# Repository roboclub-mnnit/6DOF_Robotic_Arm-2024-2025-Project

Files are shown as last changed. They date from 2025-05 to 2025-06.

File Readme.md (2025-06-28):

# 6-DOF Robotic Arm Project

This repository contains code and documentation for a 6-Degree of Freedom (6DOF) robotic arm built using MG995/MG958 servo motors and Arduino UNO. The project implements inverse kinematics and forward kinematics for precise control of the arm's end-effector position in 3D space.

---

## 📑 Table of Contents

- Project Overview
- Repository Structure
- Hardware Requirements
- Software Requirements
- Installation and Setup
- Usage
- Coordinate System and Offsets
- Kinematics and Transformation Matrices
- Angle Ranges
- Photo Gallery
---

## 📌 Project Overview

This project demonstrates the design and development of a 6DOF robotic manipulator for industrial automation tasks. It offers ±2mm positioning accuracy with a 0.5 kg payload capacity. The arm is controlled via Arduino using trajectory planning based on inverse kinematics and includes simulation in Python.

---

## Repository Structure

- `Arduino Files/`

  - `Basecode`: Firmware for  move robotic arm to given position.
  - `CODE1`: Firmware for move the robotic arm to the given postion and return in its original position.
  - `CODE2`: Firmware for move the robotic arm to given postion and pick a object and return in its original position.
  - `FINAL`: Firmware for move robotic arm from its original postion pick object from a position and place it on another position and move back to it original position.

- `Python File/`

  - `kinematics/`
    - `Inverse Kinematics.py`: Script to compute six joint angles of the robotic arm.
  - `simulation/`
    - `Simulation.py`: 3D simulation of all joint of the Robotic arm.

- `Solidworks File/`

  - (Placeholder for SolidWorks design files, e.g., `.sldprt` or `.sldasm` files)

- `docs/`

  - `ReadMe.md`: Main project overview and instructions.
  - `arduino.md`: Detailed documentation for Arduino firmware.
  - `components.md`: Information on design specifications and hardware components.
  - `python.md`: Detailed documentation for Python simulation and kinematics scripts.

## 🔧 Hardware Components

- Arduino UNO
- MG995 / MG958 Servo Motors
- Jumper Wires & Breadboard
- 3D Printed Structural Parts
- SMPS Power supply (5V)
- Ball Bearings
- Gripper (optional)

---

## 💻 Software Stack

- Arduino IDE
- BLA Library (for multiplication of mtrix in Arduino IDE)
- Python (with Matplotlib, NumPy)
- SolidWorks (for modeling)
- Inverse Kinematics (custom script)
- Forward Kinematics (DH Parameter based)

---

## 📐 Kinematics and Control

We use Denavit-Hartenberg (D-H) parameters to derive transformation matrices for forward kinematics and solve inverse kinematics numerically for joint angle calculations. The control flow is as follows:

1. **Input Desired (x, y, z)**
2. **Calculate wrist center from gripper center coordinate**
3. **Calculate first three Joint Angles via IK**
4. **Find R3_6 matrix for last three joints angle**
5. **Write Python code for simulation**
6. **Move Servo Motors via Arduino**

---

## ⚙️ Installation & Setup

1. **Python Setup**:

   - Install Python 3.x.

   - Install libraries:

     ```bash
     pip install numpy matplotlib
     ```

2. **Arduino Setup**:

   - Install Arduino IDE from arduino.cc.
   - Connect servos to Arduino pins (default: 3,5,6, 9, 10, 11).
   - Upload the appropriate `.ino` file for each leg.

3. **Simulation**:

   - Run Python scripts for visualization.
   - Adjust joint angles using sliders.

4. **Physical Robot**:

   - Power servos and connect to Arduino.
   - Use Serial Monitor (9600 baud) to input coordinates.

## Usage

### Simulation

- Run `Simulation.py` for all joint angles:

  ```bash
  python Simulation.py
  ```

  - Adjust X, Y, Z,ROLL,PITCH ,YAW values via sliders.
  - Use XY, XZ, YZ buttons to change views.
  - View end effector coordinates on the plot.

### Inverse Kinematics

- Run `Inverse Kinematics.py`:

  ```bash
  python Inverse Kinematics.py
  ```

  - Input End Effector coordinates (x, y, z) and orientation of the End Effector (ROLL,PITCH,YAW).
  - Outputs theta1, theta2, theta3, theta4, theta5, theta6 in degrees.

### Arduino Control

- Upload `.ino` file for each leg.
- Open Serial Monitor (9600 baud).
- Enter x, y, z  coordinate and ROLL,PITCH,YAW values to move servos.

## Kinematics and Transformation Matrices

Link Length: `a1 = 5.38 cm`, `a2 = 0.0 cm`, `a3 = 11.217 cm`, `a4 = 12.876 cm`, `a5 = 4.405 cm`.

### Rotation Matrices

```python
R0_1 = np.array([[-np.sin(T1), 0, np.cos(T1)],
                 [np.cos(T1),  0, np.sin(T1)],
                 [0,           1,          0]])

R1_2 = np.array([[np.cos(T2), -np.sin(T2), 0],
                 [np.sin(T2),  np.cos(T2), 0],
                 [0,           0,          1]])

R2_3 = np.array([[1, 0, 0],
                 [0, 0, 1],
                 [0, -1, 0]])
```

### DH Parameter matrix 

```python
def DH_Params_H_Matrix(i,j,q1=0,q2=0,q3=0,q4=0,q5=0,q6=0):
    DH_params=np.array([
        [q1,np.pi/2,a2,a1],
        [q2,0,a3,0],
        [q3+np.pi/2,np.pi/2,0,0],
        [q4,-np.pi/2,0,a4],
        [q5,np.pi/2,0,0],
        [q6,0,0,a5]
    ])
    H_matrix= Matrix([
        [1, 0, 0, 0],
        [0, 1, 0, 0],
        [0, 0, 1, 0],
        [0, 0, 0, 1]                                                                                   
    ])
    for k in range(i,j):                                                                                                                             
        H2_matrix=Matrix([                                     
            [np.cos(DH_params[k,0]),-np.sin(DH_params[k,0])*np.cos(DH_params[k,1]),np.sin(DH_params[k,0])*np.sin(DH_params[k,1]),DH_params[k,2]*np.cos(DH_params[k,0])],
            [np.sin(DH_params[k,0]),np.cos(DH_params[k,1])*np.cos(DH_params[k,0]),-np.cos(DH_params[k,0])*np.sin(DH_params[k,1]),DH_params[k,2]*np.sin(DH_params[k,0])],
            [0,np.sin(DH_params[k,1]),np.cos(DH_params[k,1]),DH_params[k,3]],
            [0,0,0,1]
        ])
        H_matrix=np.dot(H_matrix,H2_matrix)         
    return np.matrix(H_matrix)
```

### Rotation Matrix

```python
def get_Joint_Variables(finalX, finalY, finalZ, roll, pitch, yaw):
    R0_6_initial = np.array([
        [0, 0, 1],
        [0, -1, 0],
        [1, 0, 0]
    ])

    R_6_rotation = np.array([
        [np.cos(pitch)*np.cos(roll), np.sin(pitch)*np.sin(yaw)-np.sin(roll)*np.cos(pitch)*np.cos(yaw), np.sin(pitch)*np.cos(yaw)+np.sin(roll)*np.sin(yaw)*np.cos(pitch)],
        [np.sin(roll),               np.cos(roll)*np.cos(yaw),                                         -np.sin(yaw)*np.cos(roll)],
        [-np.sin(pitch)*np.cos(roll),np.sin(pitch)*np.sin(roll)*np.cos(yaw)+np.sin(yaw)*np.cos(pitch), -np.sin(pitch)*np.sin(roll)*np.sin(yaw)+np.cos(pitch)*np.cos(yaw)]
    ])

    R0_6 = np.dot(R0_6_initial, R_6_rotation)
    print(R0_6)

```

## Photo Gallery

- Manipulator Diagram:
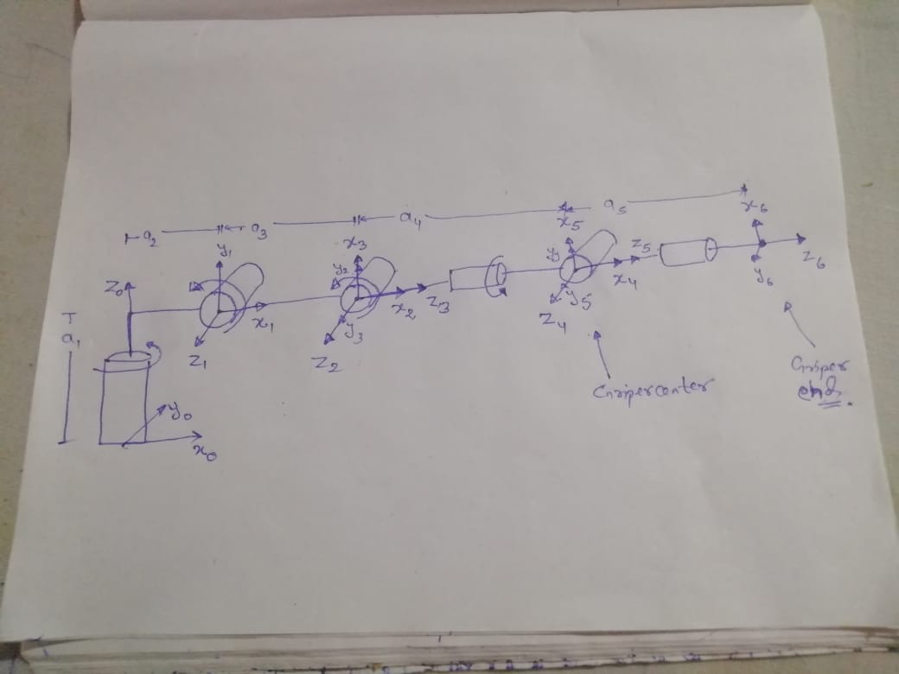
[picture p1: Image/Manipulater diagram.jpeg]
Manipulator diagram (2)
  

- Robotic Arm(Model):
  
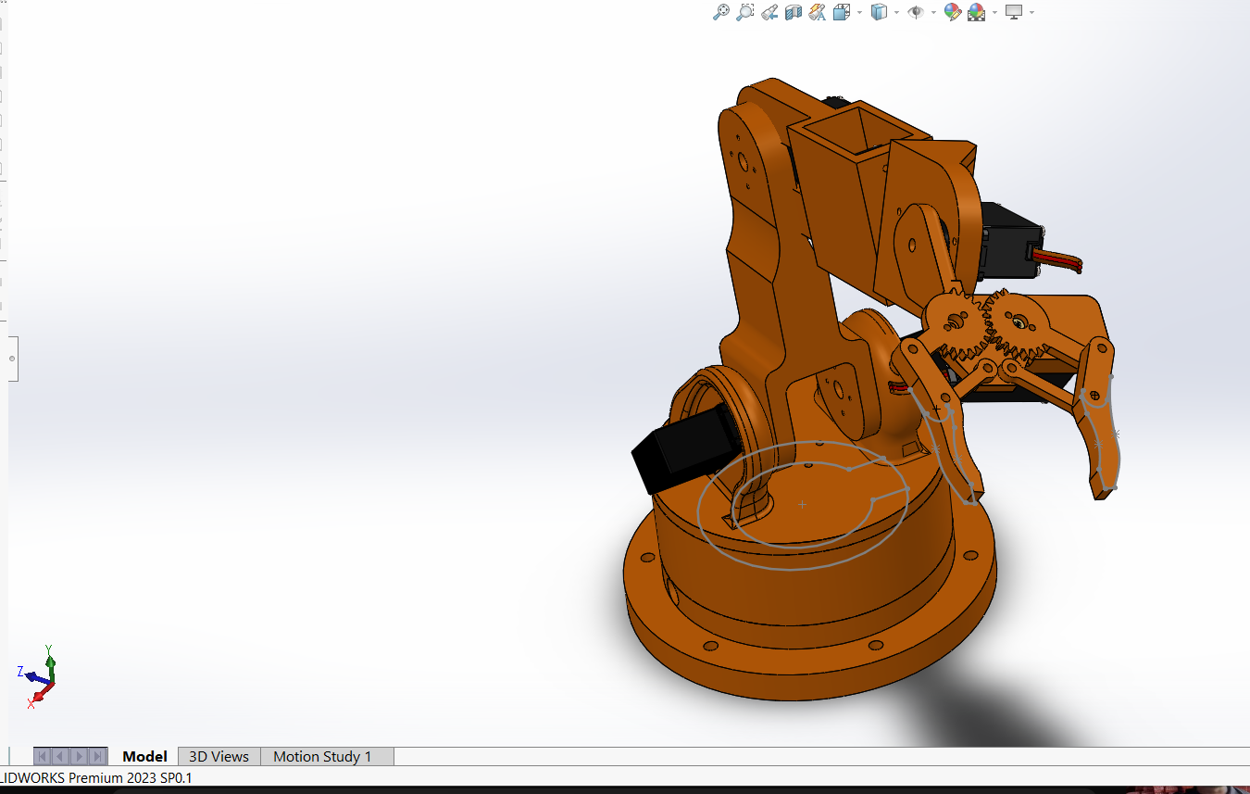
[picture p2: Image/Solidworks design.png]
Solidworks design of the 6DOFRobotic arm
  
- Robotic Arm(Actual Bot):
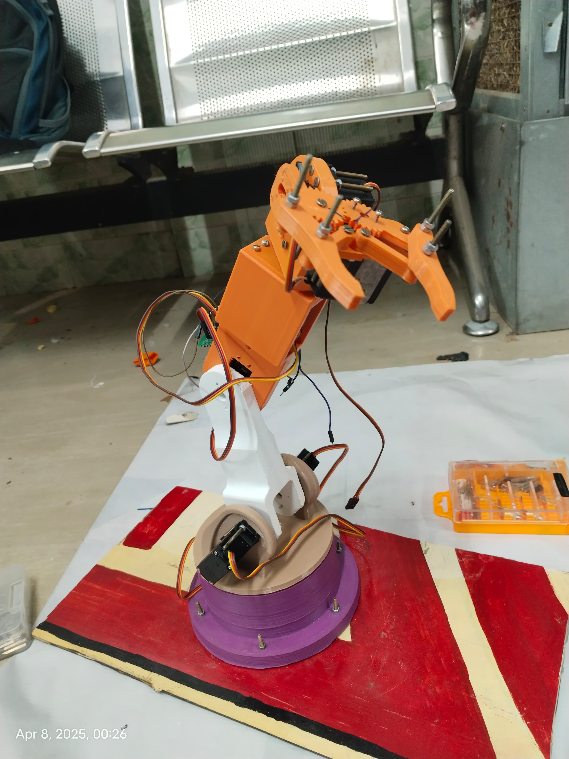
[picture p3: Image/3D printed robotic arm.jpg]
3D Printed Robotic arm


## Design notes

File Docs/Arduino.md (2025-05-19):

# Arduino Firmware Documentation

This document provides detailed explanations of the Arduino sketches used to control the 6DOF robotic arm via servo motors.

---

## 📁 Code Structure

### 🔹 `Basecode`

- **Functionality**: Moves the robotic arm to a given position based on user input (X, Y, Z, Roll, Pitch, Yaw).
- **Use Case**: For basic forward positioning.

### 🔹 `CODE1`

- **Functionality**: Moves the robotic arm to a target position and returns to the original starting position.
- **Use Case**: Simple pick-and-return operations.

### 🔹 `CODE2`

- **Functionality**: Moves the robotic arm to pick up an object and returns to its original position.
- **Use Case**: Object pickup and repositioning tasks.

### 🔹 `FINAL`

- **Functionality**: Fully automated pick-and-place operation. The arm moves from home position, picks the object, places it elsewhere, and returns.
- **Use Case**: Industrial-like automation for repetitive tasks.

---

## 🔧 Libraries Used

- **Servo.h**: For controlling servo motors.
- **BasicLinearAlgebra.h (BLA)**: Used for matrix multiplication and transformations.

---

## ⚙️ Pin Configuration

| Servo Motor | Pin Number (Default) |
|---|---|
| Base | 3 |
| Shoulder | 4,5 |
| Elbow | 6 |
| Wrist | 9 |
| Gripper | 10 |
| Rotator | 11 |

---

## 🌀 Operating Logic

1. Accept coordinates via Serial Monitor.
2. Compute required angles using inverse kinematics (in Python).
3. Pass angle values to servos.
4. Move arm to final position using the servo write command.
5. Optional: delay and return to home.

---

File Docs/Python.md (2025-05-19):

# Python Simulation and Kinematics Documentation

This file describes the Python scripts used to simulate and calculate the kinematics of the 6DOF robotic arm.

---

## 📂 Directory Structure

- `kinematics/`
  - `Inverse Kinematics.py`: Calculates the six joint angles using numerical inverse kinematics.
- `simulation/`
  - `4 Legs Simulation.py`: Generates a 3D simulation of the robotic arm’s motion using matplotlib.

---

## 🧠 Kinematics Theory

### ➤ Inverse Kinematics

The script receives:
- Target coordinates: (X, Y, Z)
- Orientation: (Roll, Pitch, Yaw)

And outputs:
- Joint angles: θ1 to θ6

It breaks down the solution in two stages:
1. **First Three Joints**: Uses geometric IK for shoulder, elbow, and base.
2. **Last Three Joints**: Uses rotation matrices to compute wrist orientation.

---

## 🧩 Libraries Used

- **NumPy**: For matrix computation
- **Matplotlib**: For 3D simulation and visualization
- **SymPy** *(optional)*: For symbolic matrix generation (used in DH transformation)

---

## 🖼️ Simulation Features

- Real-time plotting of joint configurations.
- Interactive sliders to change:
  - X, Y, Z (position)
  - Roll, Pitch, Yaw (orientation)
- XY, YZ, XZ view toggles.
- Plots the full kinematic chain of the arm.

---

## 🚀 Running the Scripts

### 1. Install Dependencies

```bash
pip install numpy matplotlib

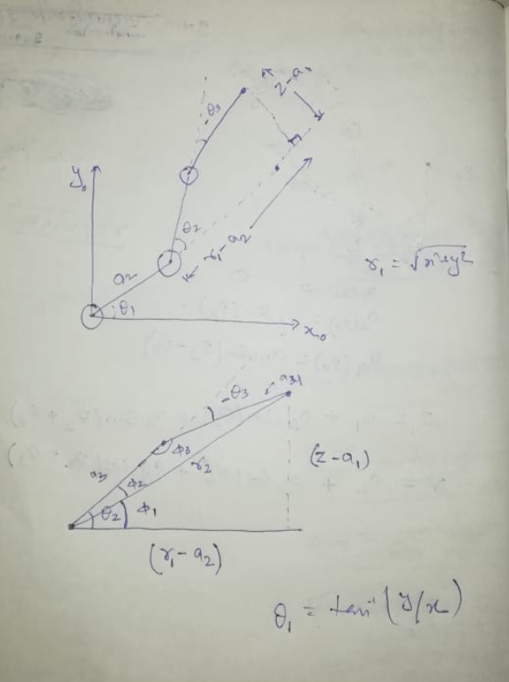
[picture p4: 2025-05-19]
Image/inverse kinamatics.png

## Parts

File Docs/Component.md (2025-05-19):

# Hardware Components and Design Specifications

This document details all the mechanical and electronic components used in building the 6DOF robotic arm.

---

## 🔩 Mechanical Components

| Component | Description |
|---|---|
| **3D Printed Links** | PLA/ABS printed arms and joints based on SolidWorks design |
| **Ball Bearings** | Used to reduce friction and improve joint motion |
| **Gripper** | Optional end-effector used to pick objects |
| **Screws & Nuts** | Fastening the servos and joints securely |
| **Base Platform** | Rigid support base for the entire arm |

---

## ⚙️ Servo Motors

| Motor Model | Specs | Used For |
|---|---|---|
| **MG995** | 13 kg.cm @ 6V, ~60° in 0.2s | General joint motion |
| **MG958** | 20+ kg.cm @ 6V, higher torque | Base and shoulder joints |

> All servos require external power using a stable **5V SMPS** or battery (not Arduino power).

---

## 💡 Electronics

| Component | Function |
|---|---|
| **Arduino UNO**  | Main microcontroller for control logic |
| **Breadboard** | Temporary connection of wires/pins |
| **Jumper Wires** | Connect servos to Arduino |
| **5V SMPS** | Power supply for all servos (stable current) |

---

## 🛠️ Design Notes

- **CAD Design**: Created in SolidWorks. (Files available in `Solidworks File/`)
- **Joint Tolerances**: Adjusted for servo horn fitment.
- **Load Testing**: Rated for 500g payload with minimal deflection.
- **Cable Management**: Ensured clearance in simulation and physical build.

---

## 🧰 Assembly Tips

- Start from the base and move upwards while assembling.
- Test each servo independently before final assembly.
- Use thread-locking adhesive on metal joints for vibration resistance.
- Ensure the gripper does not exceed torque limits.

---

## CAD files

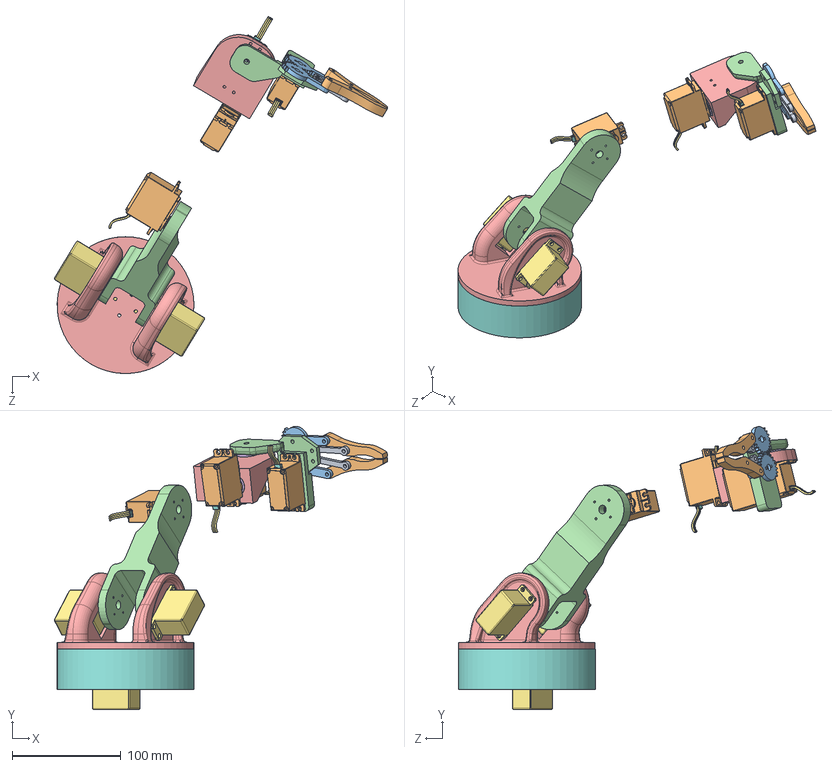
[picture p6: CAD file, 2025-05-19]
Solidwork files/final Assembly.SLDASM
307.1 x 260.9 x 328.8 mm
upper base
SERVO MOTOR x 3
bearing22
wrist (part 2)
hand2
servohorn36 x 2
MG995 x 4
Shaft x 4
Wire Boot x 4
Wires x 4
attachmentCircular x 2
gripper base
gripper gear x 2
part5 gripper x 2
Gripper link part4 x 2

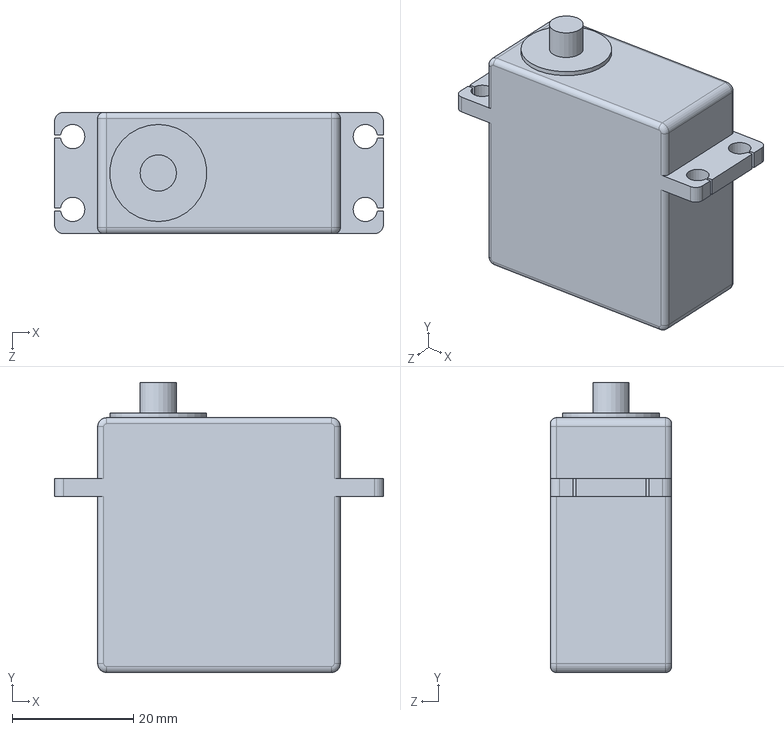
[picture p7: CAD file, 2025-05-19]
Solidwork files/SERVO MOTOR.SLDPRT
54.2 x 47.8 x 20.0 mm

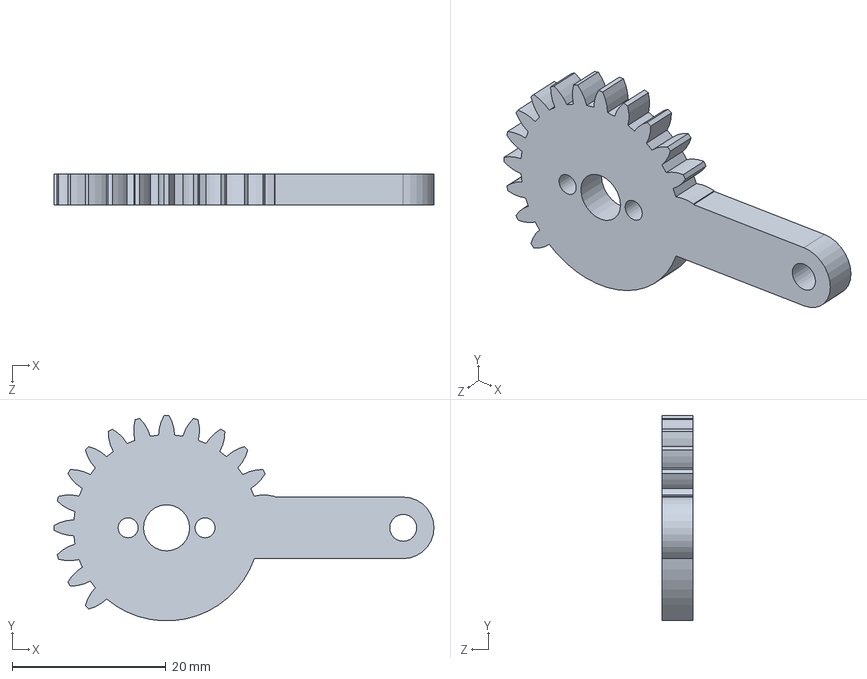
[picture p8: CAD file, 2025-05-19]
Solidwork files/gripper gear.SLDPRT
49.4 x 26.7 x 4.00 mm

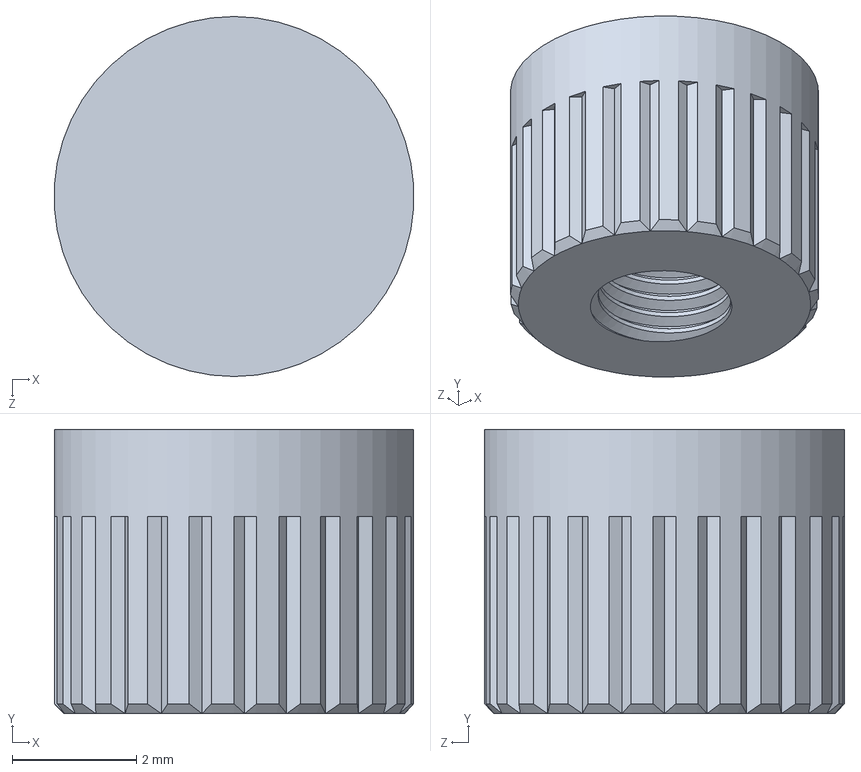
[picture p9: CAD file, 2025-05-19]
Solidwork files/Motor995/Shaft.SLDPRT
5.79 x 4.58 x 5.80 mm

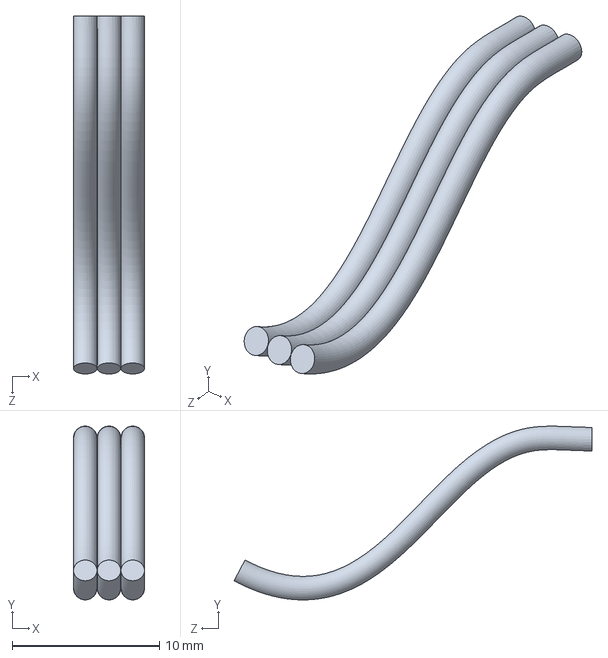
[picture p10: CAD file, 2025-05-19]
Solidwork files/Motor995/Wires.SLDPRT
4.83 x 11.8 x 24.3 mm

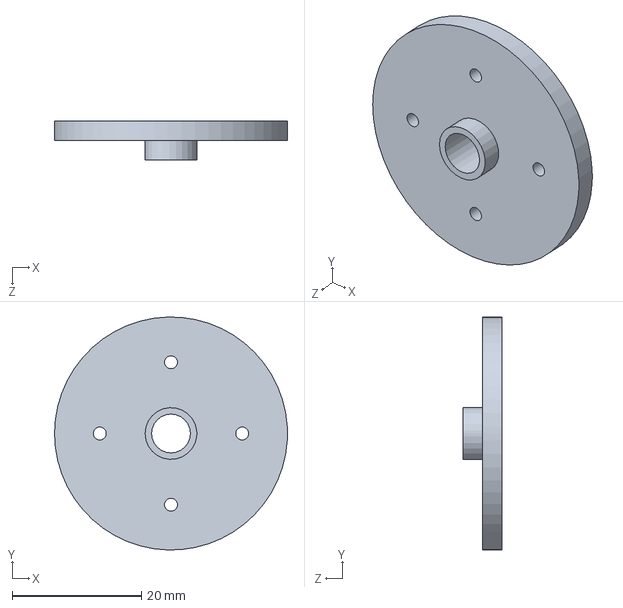
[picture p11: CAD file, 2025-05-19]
Solidwork files/servohorn36.SLDPRT
36.0 x 36.0 x 6.00 mm

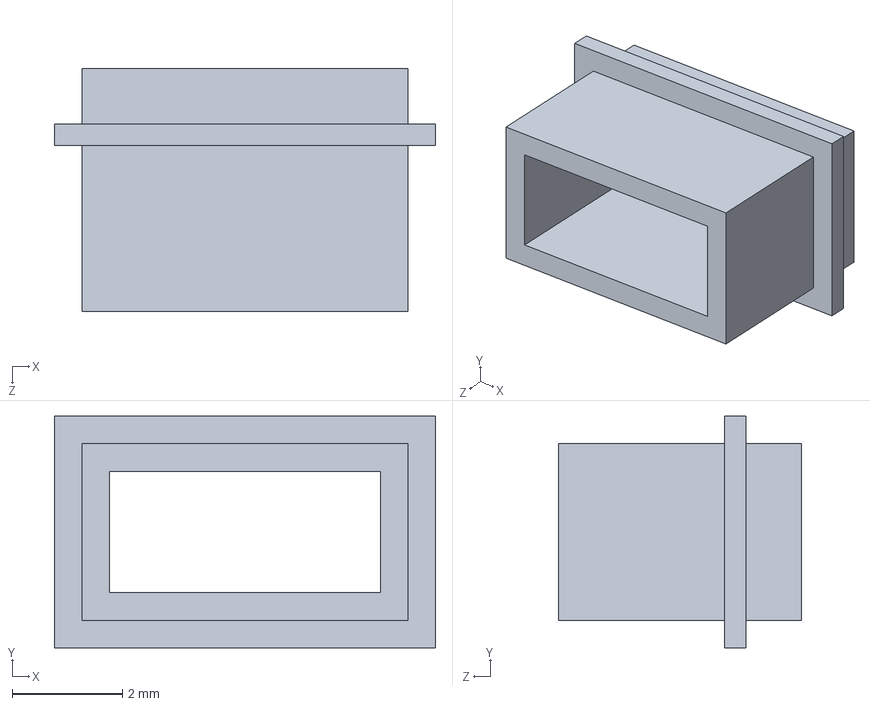
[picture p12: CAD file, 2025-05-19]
Solidwork files/Motor995/Wire Boot.SLDPRT
6.90 x 4.20 x 4.40 mm

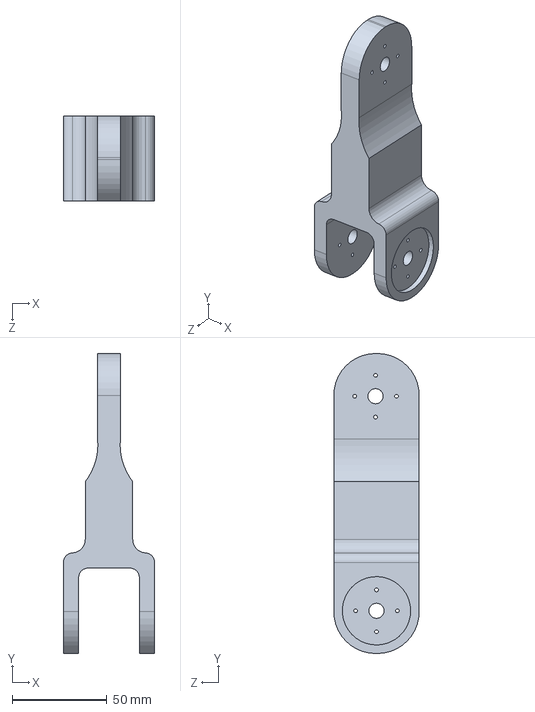
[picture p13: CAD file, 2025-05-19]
Solidwork files/hand2.SLDPRT
48.0 x 158.0 x 45.0 mm

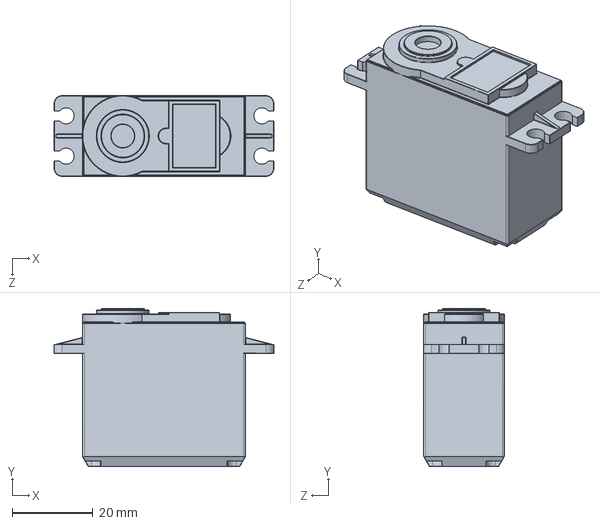
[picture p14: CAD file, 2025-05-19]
Solidwork files/Motor995/MG995.SLDPRT
54.5 x 39.2 x 20.0 mm

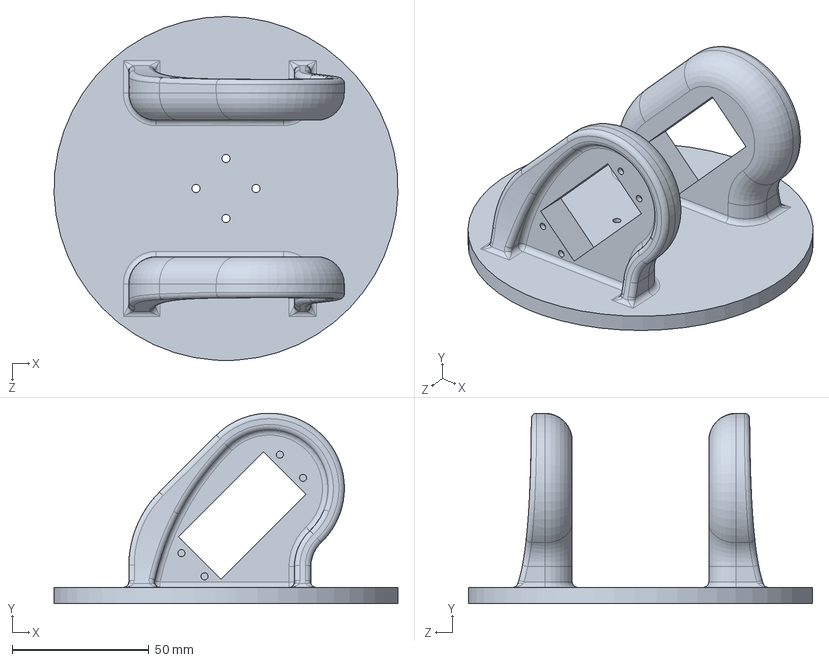
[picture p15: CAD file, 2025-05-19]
Solidwork files/wrist (part 2).SLDPRT
125.9 x 69.8 x 126.0 mm

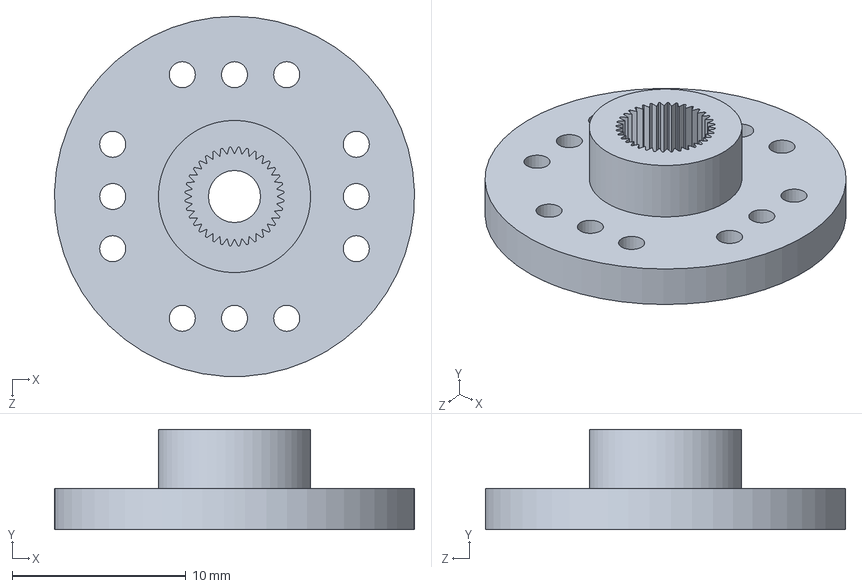
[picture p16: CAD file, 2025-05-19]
Solidwork files/attachmentCircular.SLDPRT
20.7 x 5.75 x 20.7 mm

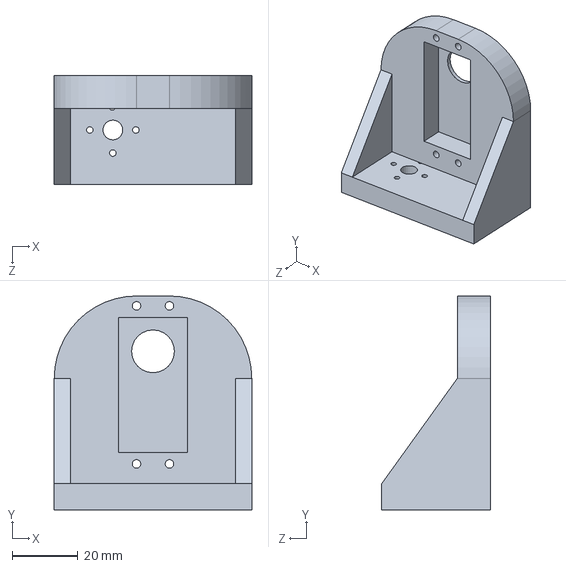
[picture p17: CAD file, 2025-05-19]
Solidwork files/part4.SLDPRT
60.0 x 65.0 x 33.0 mm

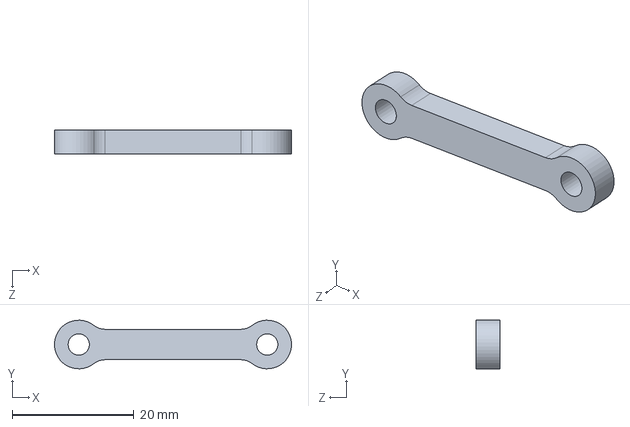
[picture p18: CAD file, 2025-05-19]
Solidwork files/Gripper link part4.SLDPRT
39.0 x 7.99 x 4.00 mm

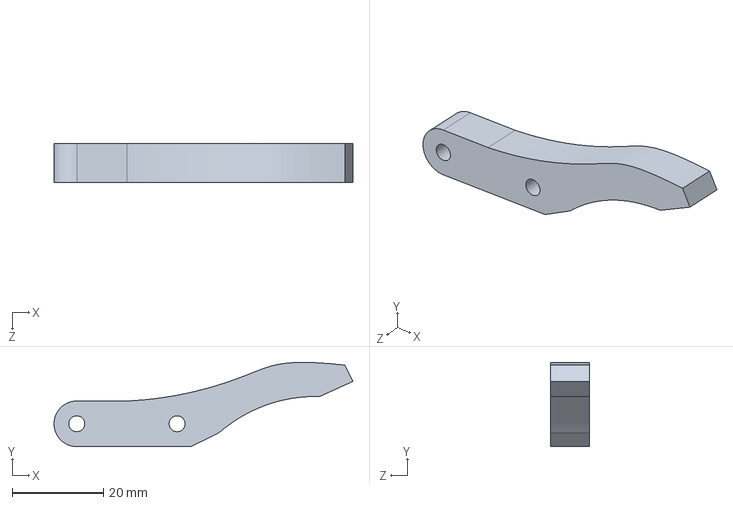
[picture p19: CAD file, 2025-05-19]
Solidwork files/part5 gripper.SLDPRT
65.5 x 18.5 x 8.50 mm

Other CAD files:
Solidwork files/Motor995/MG995 Assembly.SLDASM
Solidwork files/upper base.SLDPRT
Solidwork files/bearing22.SLDPRT
Solidwork files/gripper base.SLDPRT
Solidwork files/Motor995/pan head tapping screw_am.SLDPRT
Solidwork files/lower base.SLDPRT
Solidwork files/part3.SLDPRT

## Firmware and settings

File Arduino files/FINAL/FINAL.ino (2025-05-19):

#include <Arduino.h>
#include <BasicLinearAlgebra.h>
#include <math.h>
#include <Servo.h>  

#define NUM_SERVOS 7  // Number of joints

float theta1 =0;
float theta2 = 0;

float theta3 = 0;
float theta4 = 0;
float theta5 = 0;
float theta6 = 0;
// float theta7 = 0;

Servo servos[NUM_SERVOS];  // Array to store servo objects
int currentAngles[NUM_SERVOS] = {0, 90,90, 0, 90, 180, 90};  // Initial angles of servos
// int targetAngle[NUM_SERVOS] = {theta1, theta2, theta3, theta4, theta5, 180};  // Target angles for final position
int targetAngle[NUM_SERVOS];




// Servo pin numbers
int servoPins[NUM_SERVOS] = {3,4, 5, 6, 9, 10, 12};  

// ... [Keep all existing functions and calculations the same] ...

// Define constants
const float d1 = 5.38;
const float d2 = 0.0;
const float d3 = 11.217;
const float d4 = 12.876;
const float d5 = 4.4;
const float d6 = 0.0;

float cosineLaw(float a, float b, float c) {
    float h = acos((a * a + b * b - c * c) / (2 * a * b));
    // if(h<0){
    //   h = 180+h;
    // }
    return h;
}




// Function to calculate the rotation matrix
void ROTATION_MATRIX(float roll, float pitch, float yaw, float R0_6[3][3]) {


        // Initial rotation matrix
        float R0_6_initial[3][3] = {
          {0, 0, 1},
          {0, -1, 0},
          {1, 0, 0}
        };
      // Rotation matrix for roll, pitch, and yaw
      float R_6_rotation[3][3] = {
        {cos(pitch) * cos(roll),
        sin(pitch) * sin(yaw) - sin(roll) * cos(pitch) * cos(yaw),
        sin(pitch) * cos(yaw) + sin(roll) * sin(yaw) * cos(pitch)},

        {sin(roll),
        cos(roll) * cos(yaw),
        -sin(yaw) * cos(roll)},

        {-sin(pitch) * cos(roll),
        sin(pitch) * sin(roll) * cos(yaw) + sin(yaw) * cos(pitch),
        -sin(pitch) * sin(roll) * sin(yaw) + cos(pitch) * cos(yaw)}
      };

      // Compute the final rotation matrix R0_6 = R0_6_initial * R_6_rotation
      for (int i = 0; i < 3; i++) {
        for (int j = 0; j < 3; j++) {
          R0_6[i][j] = 0;
          for (int k = 0; k < 3; k++) {
            R0_6[i][j] +=    R_6_rotation[k][j] *R0_6_initial[i][k]  ;
            
          }
          //Serial.println(R0_6[i][j]);
        }
      }
};


//gripper coordinate using function
void calculateGripperPosition(float finalX, float finalY, float finalZ, float d5, float R0_6[3][3], float &Xgripper, float &Ygripper, float &Zgripper) {
    // Calculate the gripper position
    Xgripper = finalX - d5 * R0_6[0][2];
    Ygripper = finalY - d5 * R0_6[1][2];
    Zgripper = finalZ - d5 * R0_6[2][2];
}

float pointToRad(float p1, float p2) {
  if (p1 > 0 && p2 >= 0) {
    return atan(p2 / p1);
  } else if (p1 == 0 && p2 > 0) {
    return PI / 2;
  } else if (p1 < 0 && p2 >= 0) {
    return fabs(atan(p2 / p1)) + PI;
  } else if (p1 < 0 && p2 < 0) {
    return atan(p2 / p1) + 2 * PI;
  } else if (p1 > 0 && p2 < 0) {
    return fabs(atan(p2 / p1));
  } else if (p1 == 0 && p2 < 0) {
    return 3 * PI / 2;
  } else if (p1 == 0 && p2 == 0) {
    return 3 * PI / 2; // edge case
  }

  return 0.0; // fallback, in case no condition matches
}



void calculateInverseKinematics(float x , float y ,float z) {
    // Calculate r and s
    float r = sqrt(x * x + y * y);
    float s = z - d1;

    // Calculate r2
    float r2 = sqrt(pow(r - d2, 2) + s * s);

    // Calculate theta1, theta2, theta3

    theta1 = atan2(y, x);

    // theta1 = pointToRad( y, x);
   



    
    targetAngle[0] = degrees(theta1);
    //  if(targetAngle[0]<0){
    //   targetAngle[0] = targetAngle[0]+180;
    // }
    // else if(targetAngle[0]>180){
    //   targetAngle[0] = 180;
    // }


    float phi3 = cosineLaw(d3, d4, r2);
     theta3 = phi3-PI;

      //theta3 = (2*PI)-phi3;
    //  theta3 = acos(((r*r)+(s*s)-(d3*d3)-(d4*d4))/(2*d3*d4));
    
    

    targetAngle[3] = degrees(theta3);
    if(targetAngle[3]<0){
      targetAngle[3] = 180-(targetAngle[3]+130);
    }
    // else if(targetAngle[3]>180){
    //   targetAngle[3] = 180;
    // }
    float phi1 = atan(s / (r - d2));
    float phi2 = cosineLaw(d3, r2, d4);
    theta2 = phi1 + phi2;
    targetAngle[1] = degrees(theta2);
     targetAngle[2] = 180-targetAngle[1];

    // if(targetAngle[1]<0){
    //   targetAngle[1] = targetAngle[1]*(-1);
    //    targetAngle[2] = 180
    // -targetAngle[1];
    // }
    // else if(targetAngle[1]>180){
    //   targetAngle[1] = 180;
    // }
   
    
}



// define roation matrix (R0_1,R1_2,R2_3)for R0_3 MATRIX 

// Define matrix types using BLA library
typedef BLA::Matrix<3, 3, float> myMatrix;



    

void INVERSE_KINEMATICS_LAST_3(float  R0_6[3][3]) {
    // Compute individual rotation matrices

     
    // Rotation matrix around the z-axis FRAME 1 
    BLA::Matrix<3 ,3 > myMatrix_M1 = {1, 0, 0,0, 0, -1,0, 1, 0};
    BLA::Matrix<3,3 > myMatrix_Rz1 = {cos(theta1), -sin(theta1), 0,sin(theta1), cos(theta1), 0, 0, 0, 1};
    BLA::Matrix<3,3 > one =  myMatrix_Rz1 * myMatrix_M1;
    
    // Rotation matrix around the z-axis
    BLA::Matrix<3 ,3 > myMatrix_M2 = {1, 0, 0,0, 1, 0,0, 0, 1};
    BLA::Matrix<3,3 > myMatrix_Rz2 = {cos(theta2), -sin(theta2), 0,sin(theta2), cos(theta2), 0,0, 0, 1};
    BLA::Matrix<3,3 > two =  myMatrix_Rz2 * myMatrix_M2;

    BLA::Matrix<3 ,3 > myMatrix_M3 = {0, 0, 1,1, 0, 0,0, 1, 0};
    BLA::Matrix<3,3 > myMatrix_Rz3 = {cos(theta3), -sin(theta3), 0,sin(theta3), cos(theta3), 0,0, 0, 1};
    BLA::Matrix<3,3 > third =  myMatrix_Rz3 * myMatrix_M2;


    

    
    // Calculate R0_3
    BLA::Matrix<3,3> R0_3 = one * (two * third);  
     
    BLA::Matrix<3, 3> R0_3_new;

    for (int i = 0; i < 3; i++) {
        for (int j = 0; j < 3; j++) {
            // Shift columns: column 1 -> column 2, column 2 -> column 3, column 3 -> column 1
            R0_3_new(i, (j + 2) % 3) = R0_3(i, j);
        }
    }




   

    // Compute the inverse of R0_3                      
    BLA::Matrix<3,3 > R0_3inv = Inverse(R0_3_new);


    
                                                           
    BLA::Matrix<3, 3> R0_6M;
    for (int i = 0; i < 3; ++i) {
        for (int j = 0; j < 3; ++j) {
            R0_6M(i, j) = R0_6[i][j];
             Serial.print(R0_6[i][j]);
        } 
         Serial.println("  ");
    }

    

    // Calculate R3_6
    BLA::Matrix<3,3 > R3_6 = R0_3inv * R0_6M;

    // for(int i=0;i<3;i++){
    //   for(int j=0;j<3;j++){
    //     Serial.print(R3_6(i,j));
    //   }
    //   Serial.println(" ");
    // }
    
    
    
    
    
    // Calculate theta5
    theta5 = acos(R3_6(2, 2));
    targetAngle[5] = degrees(theta5);
    // if(targetAngle[4]<0){
    //   targetAngle[4] = targetAngle[4]+180;
    // }



    if (abs(sin(theta5)) > 1e-3) {
    theta6 = asin(R3_6(2, 1) / sin(theta5));
    targetAngle[6] = degrees(theta6);
    // if(targetAngle[5]<0){
    //   targetAngle[5] = targetAngle[5]+180;
    
    //  }
    targetAngle[6] = degrees(theta6);
    theta4 = asin(R3_6(1, 2) / sin(theta5));
    targetAngle[4] = degrees(theta4);
    // if(targetAngle[4]<0){
    //   targetAngle[4] = degrees(theta4)+180;
    // }
     }
    else {
     theta4 = atan2(R3_6(1,0), R3_6(1,1)); // Alternate calculation
     targetAngle[4] = degrees(theta4);
     }

  }


void run(float x,float y,float z){
     
      // Example R0_6 matrix (3x3)
        float R0_6[3][3];

        float roll = 0.0*M_PI/180;
        float pitch = 0.0*M_PI/180;
        float yaw = 0.0*M_PI/180;

        // Variables to hold the results
        float Xgripper, Ygripper, Zgripper;
        // call function for rotation matrix
        ROTATION_MATRIX(roll,  pitch,  yaw,  R0_6);
        // Call the function
        calculateGripperPosition(x, y, z, d5, R0_6, Xgripper, Ygripper, Zgripper);

        // call function for first three angle
        calculateInverseKinematics(Xgripper, Ygripper, Zgripper);

        // call function for last three angle
        INVERSE_KINEMATICS_LAST_3(R0_6);
        for (int i = 0; i < NUM_SERVOS; i++) {
          servos[i].attach(servoPins[i]);  // Attach servos to their respective pins 
          servos[i].write(currentAngles[i]);  // Set initial angles

          Serial.println("Target Angles: ");
          for(int i = 0; i < 7; i++)
            {
            Serial.print(targetAngle[i]);
            Serial.print(" ");
            }
          Serial.println(" ");
        }

        loop1();
}



void loop1() {
  // Move to target position
  bool allReached = false;
  while (!allReached) {
    allReached = true;
    for (int i = 0; i < NUM_SERVOS; i++) {

      if (currentAngles[i] < targetAngle[i]) {
        currentAngles[i]++;
        allReached = false;
      } else if (currentAngles[i] > targetAngle[i]) {
        currentAngles[i]--;
        allReached = false;
      }
      servos[i].write(currentAngles[i]);
    }
    
    
    delay(200);
  }
 
  servos[6].write(180);
  Serial.println("reached");
  servos[5].write(degrees(theta5)-30 );
  delay(1000);
  servos[6].write(90);
  Serial.println("Target position reached!");
  delay(2000);

  // Set target back to initial position
  
  for (int i = 0; i < NUM_SERVOS; i++) {
    currentAngles[i] = targetAngle[i];


  }

}

//   // Move back to initial position
//   allReached = false;
//   while (!allReached) {
//     allReached = true;
//     for (int i = 0; i < NUM_SERVOS; i++) {
//       if (currentAngles[i] < targetAngle[i]) {
//         currentAngles[i]++;
//         allReached = false;
//       } else if (currentAngles[i] > targetAngle[i]) {
//         currentAngles[i]--;
//         allReached = false;
//       }
//       servos[i].write(currentAngles[i]);
//     }
//     printAngles();
//     delay(200);
//   }
//    servos[6].write(180);
//   Serial.println("reached");
//   delay(1000);
//   servos[6].write(90);
//   Serial.println("Target position reached!");

//   Serial.println("Initial position reached!");
//   while(true); // Stop after completing cycle
// }
void loop2(){
     
  bool allReached = false;
  int initialAngles[NUM_SERVOS] = {0, 90,90, 0, 90, 180, 90};
  for (int i = 0; i < NUM_SERVOS; i++) {
    targetAngle[i] = initialAngles[i];


  }

  // Move back to initial position
  allReached = false;
  while (!allReached) {
    allReached = true;
    for (int i = 0; i < NUM_SERVOS; i++) {
      if (currentAngles[i] < targetAngle[i]) {
        currentAngles[i]++;
        allReached = false;
      } else if (currentAngles[i] > targetAngle[i]) {
        currentAngles[i]--;
        allReached = false;
      }
      servos[i].write(currentAngles[i]);
    }
   
    delay(200);
  }
  //  servos[6].write(180);
  // Serial.println("reached");
  // delay(1000);
  // servos[6].write(90);
  // Serial.println("Target position reached!");

  Serial.println("Initial position reached!");
  while(true); // Stop after completing cycle
}






void setup() {
  // put your setup code here, to run once:
   Serial.begin(9600);
  run(10,10,2);
  delay(500);
  run(0,12,2);
  loop2();


}

void loop() {
  // put your main code here, to run repeatedly:

}

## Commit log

2025-04-29 Arduino files
2025-04-29 Solidwork files
    [Gripper link part4.SLDPRT, MG995 Assembly.SLDASM, MG995.SLDPRT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]
